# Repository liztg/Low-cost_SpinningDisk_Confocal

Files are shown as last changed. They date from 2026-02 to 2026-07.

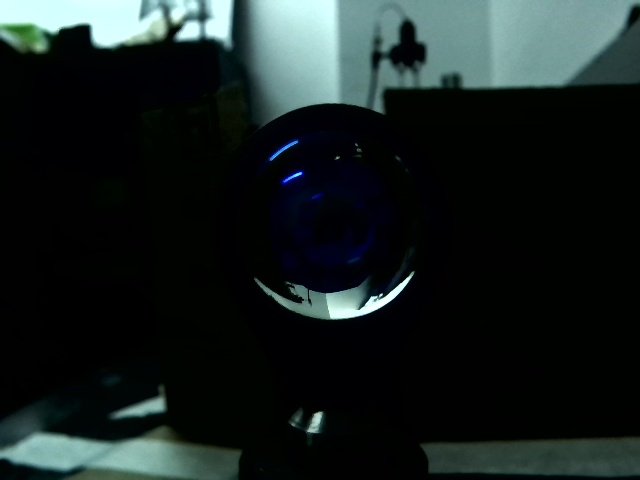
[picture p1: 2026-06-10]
Software/nipkowArduino/test/export/test_capture.jpg

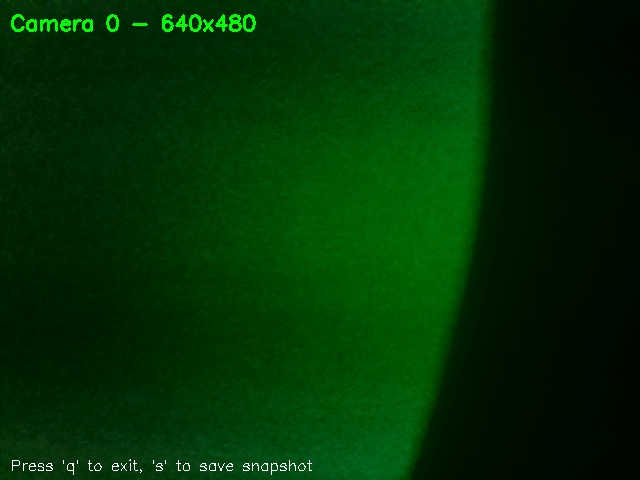
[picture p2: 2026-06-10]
Software/nipkowArduino/test/export/snapshot_20251127_172703_2.jpg

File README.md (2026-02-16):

SOFTWARE

The system integrates the control of a stepper motor (with a TB6560 driver through Arduino) and the acquisition of images with a USB camera from a unique Python interface.
It allows connecting and disconnecting devices, adjusting the motor velocity (between 0 and 300 RPM), showing live video, acquiring a series of images with manual exposure, and
to carry out different operations like average or sum to improve the signal, always saving the results with time stamps.

The software uses PySerial for the serial communication between the motor and Arduino. In controlling the camera, it uses opencv-python (OpenCV) for the detection, capture, and
visualization of images, and Numpy for the processing. It also uses standard utilities of Python, like Datetime for the names of the files and for time management.

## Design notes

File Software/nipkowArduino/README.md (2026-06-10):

# Arduino Stepper Motor & Camera Control System

Sistema integrado para control de motor stepper mediante Arduino con driver A4988 y captura de imágenes con cámara USB, controlado desde Python via comunicación serial.

## 📋 Componentes Necesarios

### Hardware Stepper
- Arduino (Uno, Nano, Mega, etc.)
- Driver TB6560 (o TB6600)
- Motor stepper (NEMA 17, NEMA 23, etc.)
- Fuente de alimentación (12-36V DC para el motor)
- Cables de conexión

### Hardware Cámara
- Cámara USB compatible con Windows
- Puerto USB disponible

## 🔌 Conexiones Hardware

### TB6560 a Arduino
```
TB6560 PUL+ (CLK+)  -> Arduino Pin 3
TB6560 DIR+ (CW+)   -> Arduino Pin 4
TB6560 ENA+         -> Arduino Pin 5 (opcional)
TB6560 PUL-         -> Arduino GND
TB6560 DIR-         -> Arduino GND
TB6560 ENA-         -> Arduino GND
```

### TB6560 a Motor y Alimentación
```
TB6560 VCC   -> Fuente de alimentación + (12-36V DC)
TB6560 GND   -> Fuente de alimentación -
TB6560 A+, A- -> Bobina A del motor
TB6560 B+, B- -> Bobina B del motor
```

### Configuración del TB6560
⚠️ **IMPORTANTE**: 
- **Ajustar corriente**: Usar los DIP switches según las especificaciones de tu motor
- **Microstepping**: Configurar según necesites (1, 2, 4, 8, 16 pasos)
- **Voltaje**: Verificar que la fuente esté dentro del rango 12-36V DC

## 🚀 Instalación

### 1. Clonar o descargar el proyecto
```bash
cd nipkowArduino
```

### 2. Instalar dependencias Python
```bash
pip install -r requirements.txt
```

### 3. Cargar código al Arduino
1. Abre `arduino_stepper/arduino_stepper.ino` en Arduino IDE
2. Conecta tu Arduino por USB
3. Selecciona el puerto COM correcto en Herramientas > Puerto
4. Haz clic en "Cargar" (Upload)

## 💻 Uso

### Ejecutar la Aplicación Principal

El sistema se controla mediante comandos de texto:

```bash
python main.py
```

### Interfaz de Comandos

```
>>> help

CONNECTION:
  connect <PORT>              - Connect to Arduino
  cam                         - Connect to camera (auto-detect)
  cam <INDEX>                 - Connect to specific camera
  disconnect                  - Disconnect all devices

STEPPER MOTOR:
  speed <RPM>                 - Set motor speed
  stop                        - Stop motor immediately
  status                      - Show motor status

CAMERA:
  capture <N> <EXP> avg       - Capture N images, exposure EXP ms, average
  capture <N> <EXP> sum       - Capture N images, exposure EXP ms, sum
  live                        - Show live video feed
  list-cam                    - List available cameras

SYSTEM:
  info                        - Show system status
  help                        - Show this help
  exit                        - Exit program
```

### Flujo de Trabajo Típico

#### 1. Conectar Dispositivos
```
>>> connect COM3
Connecting to COM3...
Connected to stepper on COM3

>>> cam
Connecting to camera...
Camera connected: Index 0, 1920x1080
```

#### 2. Controlar Motor Stepper
```
>>> speed 150
Arduino: Speed set to 150 RPM

>>> status
Motor Status:
   Speed: 150 RPM
   State: CW
   Running: Yes

>>> stop
Stopping motor...
Arduino: Speed set to 0 RPM
```

#### 3. Capturar y Procesar Imágenes
```
>>> capture 10 100 avg
Starting capture: 10 images @ 100ms...

Capturing 10 images with timing measurement...
============================================================
  Image 1/10 | Capture: 45.23ms | Interval: N/A (first)
  Image 2/10 | Capture: 43.87ms | Interval: 545.12ms
  ...
============================================================
CAPTURE STATISTICS
============================================================
Images captured: 10/10
Total burst time: 5.432s (5432.15ms)

INDIVIDUAL CAPTURE TIMES:
  Average: 44.28ms
  Min: 43.87ms
  Max: 45.67ms

INTER-CAPTURE INTERVALS:
  Average: 544.33ms
  Min: 543.98ms
  Max: 545.12ms

Effective FPS: 1.84
============================================================

Averaging 10 images...
Successfully averaged 10 images -> output_averaged_20251126_143052.jpg

Save timing statistics to file? (y/n): y
Statistics saved to: capture_stats_20251126_143052.txt
```

#### 4. Vista en Vivo
```
>>> live
Starting live video...
Controls:
  'q' or ESC - Exit live view
  's' - Save snapshot

[Ventana de OpenCV se abre]
[Presionar 's' para guardar snapshot]
Snapshot saved: snapshot_20251126_143215_1.jpg
[Presionar 'q' para salir]
```

#### 5. Ver Estado del Sistema
```
>>> info
==================================================
SYSTEM STATUS
==================================================
[OK] Stepper: Connected
  Speed: 0 RPM
  State: STOPPED
[OK] Camera: Connected (Index 0)
  Resolution: 1920x1080
==================================================
```

### Uso Avanzado - Módulos Independientes

#### Solo Control de Stepper
```bash
python stepper_control.py
```

#### Solo Control de Cámara
```bash
python camera_controller.py
```

## 🎯 Casos de Uso

### Fotografía de Larga Exposición
```
>>> cam
>>> capture 10 200 avg
```
1. Conectar cámara
2. Capturar 10 imágenes con exposición de 200ms
3. Promediar para reducir ruido
4. Resultado guardado automáticamente

### Astrofotografía
```
>>> cam
>>> capture 30 500 sum
```
1. Capturar 30 frames con exposición de 500ms
2. Sumar imágenes para aumentar señal
3. Resultado normalizado automáticamente

### Time-Lapse con Motor
```
>>> connect COM3
>>> cam
>>> speed 10
>>> capture 100 100 avg
>>> stop
```
1. Configurar stepper para rotación lenta (10 RPM)
2. Capturar 100 imágenes promediadas
3. Detener motor al finalizar

### Escaneo Panorámico
```
>>> connect COM3
>>> cam
>>> live              # Verificar encuadre primero
>>> speed 20
>>> capture 50 200 avg
>>> stop
```

## ⚙️ Configuración

### Parámetros de Cámara

#### Exposición Manual
- Rango típico: 1-1000 ms
- Para fotografía nocturna: 100-500 ms
- Para objetos en movimiento: 1-50 ms

#### Número de Imágenes
- Promediado (reducir ruido): 5-20 imágenes
- Suma (astrofotografía): 10-50 imágenes
- Más imágenes = mejor calidad pero más tiempo

### Cambiar Pasos por Revolución
Si tu motor tiene diferente número de pasos (por ejemplo, 400 pasos):

En `arduino_stepper.ino` línea 19:
```cpp
const int STEPS_PER_REVOLUTION = 200;  // Cambiar según tu motor
```

### Cambiar Pines
Modifica las definiciones en `arduino_stepper.ino` líneas 15-17:
```cpp
const int STEP_PIN = 3;   // PUL+ on TB6560
const int DIR_PIN = 4;    // DIR+ on TB6560
const int ENABLE_PIN = 5; // ENA+ on TB6560
```

### Cambiar Dirección de Rotación
En `arduino_stepper.ino` línea 26:
```cpp
digitalWrite(DIR_PIN, HIGH);  // HIGH = horario, LOW = antihorario
```

## 🔧 Resolución de Problemas

### Cámara

#### No se detecta la cámara
- Verifica que esté conectada al USB
- Prueba con otro puerto USB
- Cierra otras aplicaciones que puedan estar usando la cámara
- Verifica que los drivers estén instalados

#### Las imágenes salen muy oscuras/claras
- Ajusta el tiempo de exposición
- Valores más altos = más luz capturada
- Prueba con diferentes tiempos

#### Error al guardar imágenes
- Verifica permisos de escritura en el directorio
- Asegúrate de tener espacio en disco

### Motor Stepper
- Verifica las conexiones
- Comprueba que la alimentación del motor esté conectada
- Ajusta la corriente del A4988
- Verifica que ENABLE esté en LOW (motor habilitado)

#### El motor no gira
- Verifica las conexiones (PUL+, DIR+, ENA+ a Arduino y todos los - a GND)
- Comprueba que la alimentación del motor esté conectada (12-36V DC)
- Ajusta la corriente mediante DIP switches del TB6560
- Verifica que ENABLE esté en LOW (motor habilitado)
- Asegúrate de conectar correctamente PUL-, DIR-, ENA- a GND del Arduino

#### El motor vibra pero no gira
- La velocidad puede ser demasiado alta
- Reduce el RPM
- Ajusta la corriente mediante DIP switches del TB6560
- Verifica la configuración de microstepping
- Asegúrate de que las conexiones A+/A- y B+/B- sean correctas

#### Error al conectar por serial
- Verifica el puerto COM correcto
- Cierra otras aplicaciones que puedan estar usando el puerto (Arduino IDE Serial Monitor)
- Asegúrate de que los drivers del Arduino estén instalados

#### El motor pierde pasos
- Reduce la velocidad
- Ajusta la corriente del TB6560 (aumentar ligeramente)
- Verifica que la carga mecánica no sea excesiva
- Reduce el microstepping o aumenta el voltaje de alimentación

## 📝 Estructura del Proyecto

```
nipkowArduino/
├── main.py                     # Aplicación principal unificada
├── stepper_control.py          # Módulo control stepper
├── camera_controller.py        # Módulo control cámara
├── arduino_stepper/
│   └── arduino_stepper.ino     # Código Arduino
├── requirements.txt            # Dependencias Python
├── .gitignore
├── README.md
└── .github/
    └── copilot-instructions.md
```

## 📋 Referencia de Comandos

### Comandos de Conexión

| Comando | Descripción | Ejemplo |
|---|---|---|
| `connect <PORT>` | Conectar Arduino en puerto especificado | `connect COM3` |
| `cam` | Conectar cámara (auto-detecta) | `cam` |
| `cam <INDEX>` | Conectar cámara específica | `cam 0` |
| `disconnect` | Desconectar todos los dispositivos | `disconnect` |

### Comandos de Motor

| Comando | Descripción | Ejemplo |
|---|---|---|
| `speed <RPM>` | Establecer velocidad (0-300 RPM) | `speed 100` |
| `stop` | Parada de emergencia | `stop` |
| `status` | Ver estado del motor | `status` |

### Comandos de Cámara

| Comando | Descripción | Ejemplo |
|---|---|---|
| `capture <N> <EXP> avg` | Capturar N imágenes, promediar | `capture 10 100 avg` |
| `capture <N> <EXP> sum` | Capturar N imágenes, sumar | `capture 20 50 sum` |
| `live` | Vista en vivo | `live` |
| `list-cam` | Listar cámaras disponibles | `list-cam` |

### Comandos de Sistema

| Comando | Descripción | Ejemplo |
|---|---|---|
| `info` | Estado completo del sistema | `info` |
| `help` o `?` | Mostrar ayuda | `help` |
| `exit` o `quit` | Salir del programa | `exit` |

### Archivos Generados

| Archivo | Descripción |
|---|---|
| `output_averaged_YYYYMMDD_HHMMSS.jpg` | Imágenes promediadas |
| `output_summed_YYYYMMDD_HHMMSS.jpg` | Imágenes sumadas |
| `snapshot_YYYYMMDD_HHMMSS_N.jpg` | Snapshots desde live view |
| `capture_stats_YYYYMMDD_HHMMSS.txt` | Estadísticas de timing |

### Medición de Tiempos

Cada captura registra:
- **Tiempo individual** de cada imagen (ms)
- **Intervalo exacto** entre capturas consecutivas (ms)
- **Tiempo total** de la ráfaga (ms/s)
- **Estadísticas**: promedio, mínimo, máximo
- **FPS efectivo** de la captura

Ejemplo de estadísticas guardadas:
```
CAPTURE BURST STATISTICS
============================================================

Date/Time: 2025-11-26 14:30:52
Images captured: 10/10
Total burst time: 5.432156s (5432.156ms)

INDIVIDUAL CAPTURE TIMES (ms):
  Image 1: 45.234ms
  Image 2: 43.871ms
  Image 3: 44.012ms
  ...

AVERAGE: 44.283ms
MIN: 43.871ms
MAX: 45.671ms

INTER-CAPTURE INTERVALS (ms):
  Interval 1-2: 545.123ms
  Interval 2-3: 543.987ms
  ...

AVERAGE: 544.332ms
MIN: 543.987ms
MAX: 546.012ms

EFFECTIVE FPS: 1.841
```

## 🎓 Funcionalidades Principales

### Control de Stepper
- ✅ Comunicación serial bidireccional con Arduino
- ✅ Control de velocidad en RPM (0-300)
- ✅ Lectura de confirmaciones del Arduino
- ✅ Parada de emergencia
- ✅ Monitoreo de estado en tiempo real
- ✅ Interfaz por comandos de texto

### Control de Cámara
- ✅ Detección automática de cámaras USB
- ✅ Control de exposición manual
- ✅ Captura múltiple de imágenes
- ✅ Promediado de imágenes (reducir ruido)
- ✅ Suma de imágenes (aumentar señal)
- ✅ Vista en vivo con OpenCV
- ✅ Captura de snapshots durante live view
- ✅ Guardado automático con timestamp
- ✅ Normalización automática
- ✅ **Medición precisa de tiempos de captura**
- ✅ **Estadísticas detalladas de intervalos**
- ✅ **Exportación de estadísticas a archivo**

## 📚 Recursos Adicionales

- [Datasheet TB6560](https://www.epitran.it/ebayDrive/TB6560.pdf)
- [TB6600 Manual](https://www.dfrobot.com/wiki/index.php/TB6600_Stepper_Motor_Driver_SKU:_DRI0043)
- [PySerial Documentation](https://pyserial.readthedocs.io/)
- [OpenCV Python Tutorials](https://docs.opencv.org/4.x/d6/d00/tutorial_py_root.html)
- [Arduino Serial Reference](https://www.arduino.cc/reference/en/language/functions/communication/serial/)
- [NumPy Documentation](https://numpy.org/doc/)

## 🔬 Aplicaciones

- **Astrofotografía**: Captura y suma de múltiples exposiciones
- **Fotografía de larga exposición**: Reducción de ruido mediante promediado
- **Time-lapse**: Sincronización de motor y captura de imágenes
- **Escaneo panorámico**: Control preciso de rotación con captura
- **Microscopía**: Control de iluminación y captura automática

## 📄 Licencia

Este proyecto es de código abierto y está disponible bajo la licencia MIT.

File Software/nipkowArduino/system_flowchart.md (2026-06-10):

# Diagrama de Flujo del Sistema de Control

## Arquitectura General del Sistema

```mermaid
graph TB
    subgraph "Usuario"
        USER[Usuario]
    end
    
    subgraph "Aplicación Python - main.py"
        CLI[Interfaz de Comandos CLI]
        PARSER[Parser de Comandos]
        MAIN[MainController]
    end
    
    subgraph "Módulos de Control"
        STEPPER[StepperController]
        CAMERA[CameraController]
    end
    
    subgraph "Hardware"
        ARDUINO[Arduino + TB6560]
        MOTOR[Motor Stepper]
        CAM[Cámara USB]
    end
    
    subgraph "Salidas"
        IMG[Imágenes Procesadas]
        STATS[Estadísticas de Timing]
        SNAP[Snapshots]
    end
    
    USER -->|Comandos de texto| CLI
    CLI --> PARSER
    PARSER --> MAIN
    
    MAIN -->|Comandos de motor| STEPPER
    MAIN -->|Comandos de cámara| CAMERA
    
    STEPPER <-->|Serial 9600 baud| ARDUINO
    ARDUINO -->|Pulsos STEP/DIR| MOTOR
    
    CAMERA <-->|USB / OpenCV| CAM
    
    CAMERA --> IMG
    CAMERA --> STATS
    CAMERA --> SNAP
```

## Flujo de Inicio del Sistema

```mermaid
flowchart TD
    START([Ejecutar python main.py]) --> INIT[Inicializar MainController]
    INIT --> WELCOME[Mostrar mensaje de bienvenida]
    WELCOME --> PROMPT[Mostrar prompt: >>>]
    PROMPT --> WAIT{Esperar entrada<br/>de usuario}
    
    WAIT -->|Comando recibido| PARSE[Parsear comando]
    PARSE --> VALIDATE{¿Comando<br/>válido?}
    
    VALIDATE -->|No| ERROR[Mostrar error]
    ERROR --> PROMPT
    
    VALIDATE -->|Sí| DISPATCH[Despachar a handler]
    DISPATCH --> EXEC[Ejecutar comando]
    EXEC --> RESULT[Mostrar resultado]
    RESULT --> PROMPT
    
    WAIT -->|Ctrl+C o EOF| CLEANUP[Cleanup: cerrar dispositivos]
    CLEANUP --> END([Salir])
```

## Flujo de Conexión de Dispositivos

```mermaid
flowchart TD
    subgraph "Conexión Arduino"
        CONN_START[Comando: connect COM3] --> OPEN_SERIAL[Abrir puerto serial]
        OPEN_SERIAL --> WAIT_RESET[Esperar 2s para reset]
        WAIT_RESET --> READ_INIT[Leer mensaje inicial]
        READ_INIT --> CONN_OK[Stepper conectado]
    end
    
    subgraph "Conexión Cámara"
        CAM_START[Comando: cam] --> DETECT[Detectar cámaras USB]
        DETECT --> CHECK{¿Cámaras<br/>encontradas?}
        CHECK -->|No| CAM_ERROR[Error: sin cámaras]
        CHECK -->|Sí| SELECT[Seleccionar cámara]
        SELECT --> OPEN_CAM[Abrir VideoCapture]
        OPEN_CAM --> GET_INFO[Obtener resolución/info]
        GET_INFO --> CAM_OK[Cámara conectada]
    end
```

## Flujo de Control de Motor Stepper

```mermaid
flowchart TD
    SPEED_CMD[Comando: speed 150] --> CHECK_CONN{¿Stepper<br/>conectado?}
    CHECK_CONN -->|No| ERR1[Error: no conectado]
    
    CHECK_CONN -->|Sí| VALIDATE_RPM{¿RPM válido<br/>0-300?}
    VALIDATE_RPM -->|No| ERR2[Advertencia: valor fuera de rango]
    ERR2 --> CLAMP[Ajustar a rango válido]
    
    VALIDATE_RPM -->|Sí| CLAMP
    CLAMP --> BUILD_CMD[Construir comando: SPEED:150]
    BUILD_CMD --> SEND[Enviar por serial]
    SEND --> FLUSH[Flush buffer]
    FLUSH --> WAIT_RESP[Esperar respuesta Arduino]
    
    WAIT_RESP --> READ{¿Respuesta<br/>recibida?}
    READ -->|No| TIMEOUT[Advertencia: sin respuesta]
    READ -->|Sí| PARSE_RESP[Parsear respuesta]
    PARSE_RESP --> UPDATE[Actualizar estado interno]
    UPDATE --> SHOW[Mostrar confirmación]
    
    subgraph "Arduino"
        ARD_RECV[Recibir comando serial] --> ARD_PARSE[Parsear SPEED:XXX]
        ARD_PARSE --> ARD_CALC[Calcular delay entre pasos]
        ARD_CALC --> ARD_SET[Configurar stepDelay]
        ARD_SET --> ARD_SEND[Enviar confirmación]
        ARD_SEND --> ARD_LOOP[Loop: generar pulsos STEP]
    end
```

## Flujo de Captura de Imágenes

```mermaid
flowchart TD
    CAPTURE_CMD[Comando: capture 10 100 avg] --> PARSE_ARGS[Parsear argumentos]
    PARSE_ARGS --> EXTRACT[Extraer: N=10, EXP=100ms, MODE=avg]
    
    EXTRACT --> CHECK_CAM{¿Cámara<br/>conectada?}
    CHECK_CAM -->|No| ERR_CAM[Error: cámara no conectada]
    
    CHECK_CAM -->|Sí| SET_EXP[Configurar exposición manual]
    SET_EXP --> WAIT_CAM[Esperar ajuste de cámara 0.5s]
    WAIT_CAM --> INIT_STATS[Inicializar arrays de estadísticas]
    
    INIT_STATS --> START_TIMER[Iniciar timer de ráfaga]
    START_TIMER --> LOOP_START{i < N?}
    
    LOOP_START -->|No| LOOP_END[Fin de captura]
    LOOP_START -->|Sí| TIMER1[Timestamp inicial]
    
    TIMER1 --> CAP[Capturar imagen]
    CAP --> TIMER2[Timestamp final]
    TIMER2 --> CALC_TIME[Calcular tiempo de captura]
    CALC_TIME --> STORE_IMG[Guardar imagen en array]
    STORE_IMG --> STORE_TIME[Guardar tiempo en array]
    
    STORE_TIME --> CALC_INT{¿i > 0?}
    CALC_INT -->|Sí| CALC_INTERVAL[Calcular intervalo desde anterior]
    CALC_INTERVAL --> STORE_INT[Guardar intervalo]
    CALC_INT -->|No| SKIP_INT[Intervalo = N/A]
    
    STORE_INT --> PRINT[Imprimir estadísticas de imagen]
    SKIP_INT --> PRINT
    PRINT --> DELAY[Delay entre capturas]
    DELAY --> INCREMENT[i++]
    INCREMENT --> LOOP_START
    
    LOOP_END --> END_TIMER[Finalizar timer total]
    END_TIMER --> CALC_STATS[Calcular estadísticas]
    CALC_STATS --> PRINT_STATS[Imprimir estadísticas completas]
    
    PRINT_STATS --> PROCESS{Modo de<br/>procesamiento}
    PROCESS -->|avg| AVG[Promediar imágenes]
    PROCESS -->|sum| SUM[Sumar imágenes]
    
    AVG --> SAVE_IMG[Guardar imagen procesada]
    SUM --> SAVE_IMG
    
    SAVE_IMG --> ASK{¿Guardar<br/>estadísticas?}
    ASK -->|Sí| SAVE_STATS[Guardar archivo .txt]
    ASK -->|No| DONE[Finalizado]
    SAVE_STATS --> DONE
```

## Flujo de Vista en Vivo (Live View)

```mermaid
flowchart TD
    LIVE_CMD[Comando: live] --> CHECK_CAM{¿Cámara<br/>conectada?}
    CHECK_CAM -->|No| ERR[Error: cámara no conectada]
    
    CHECK_CAM -->|Sí| SHOW_INST[Mostrar instrucciones]
    SHOW_INST --> WAIT_USER[Esperar usuario presione tecla]
    WAIT_USER --> INIT_WIN[Crear ventana OpenCV]
    
    INIT_WIN --> LOOP{Loop infinito}
    LOOP --> READ_FRAME[Leer frame de cámara]
    READ_FRAME --> CHECK_FRAME{¿Frame<br/>válido?}
    
    CHECK_FRAME -->|No| ERR_FRAME[Error: frame inválido]
    ERR_FRAME --> EXIT
    
    CHECK_FRAME -->|Sí| OVERLAY[Agregar info overlay]
    OVERLAY --> DISPLAY[Mostrar en ventana]
    DISPLAY --> KEY[Leer tecla con waitKey(1)]
    
    KEY --> CHECK_KEY{¿Qué tecla?}
    CHECK_KEY -->|'q' o ESC| EXIT[Salir de live view]
    CHECK_KEY -->|'s'| SNAP[Guardar snapshot]
    CHECK_KEY -->|Otra| LOOP
    
    SNAP --> GEN_NAME[Generar nombre con timestamp]
    GEN_NAME --> SAVE_SNAP[Guardar snapshot]
    SAVE_SNAP --> PRINT_SNAP[Imprimir confirmación]
    PRINT_SNAP --> LOOP
    
    EXIT --> DESTROY[Destruir ventanas OpenCV]
    DESTROY --> CLEAR[Limpiar buffers]
    CLEAR --> DONE[Retornar a prompt]
```

## Flujo de Procesamiento de Imágenes

```mermaid
flowchart TD
    START[Array de imágenes capturadas] --> CHECK{¿Modo de<br/>procesamiento?}
    
    subgraph "Promediado (avg)"
        AVG_START[Modo: average] --> CONVERT_F[Convertir a float]
        CONVERT_F --> MEAN[np.mean(images, axis=0)]
        MEAN --> CONVERT_U8[Convertir a uint8]
        CONVERT_U8 --> AVG_RESULT[Imagen promediada]
    end
    
    subgraph "Suma (sum)"
        SUM_START[Modo: sum] --> SUM_F[Sumar como float64]
        SUM_F --> NORMALIZE{¿Normalizar?}
        NORMALIZE -->|Sí| NORM[Normalizar 0-255]
        NORMALIZE -->|No| CLIP[Clip 0-255]
        NORM --> SUM_RESULT[Imagen sumada]
        CLIP --> SUM_RESULT
    end
    
    CHECK -->|avg| AVG_START
    CHECK -->|sum| SUM_START
    
    AVG_RESULT --> SAVE
    SUM_RESULT --> SAVE
    
    SAVE[cv2.imwrite] --> TIMESTAMP[Generar nombre con timestamp]
    TIMESTAMP --> FILE[Guardar archivo JPG]
```

## Estados del Sistema

```mermaid
stateDiagram-v2
    [*] --> Desconectado
    
    Desconectado --> StepperConectado: connect COM3
    Desconectado --> CamaraConectada: cam
    
    StepperConectado --> Ambos: cam
    CamaraConectada --> Ambos: connect COM3
    
    StepperConectado --> MotorActivo: speed > 0
    MotorActivo --> StepperConectado: speed 0 / stop
    
    CamaraConectada --> Capturando: capture
    Capturando --> CamaraConectada: fin de captura
    
    CamaraConectada --> VistaEnVivo: live
    VistaEnVivo --> CamaraConectada: 'q' / ESC
    
    Ambos --> MotorYCaptura: speed > 0 && capture
    MotorYCaptura --> Ambos: fin
    
    StepperConectado --> Desconectado: disconnect
    CamaraConectada --> Desconectado: disconnect
    Ambos --> Desconectado: disconnect
    MotorActivo --> Desconectado: disconnect (auto-stop)
    
    Desconectado --> [*]: exit
    StepperConectado --> [*]: exit
    CamaraConectada --> [*]: exit
    Ambos --> [*]: exit
```

## Diagrama de Secuencia - Captura Completa

```mermaid
sequenceDiagram
    actor Usuario
    participant CLI as CLI/Main
    participant Camera as CameraController
    participant USB as Cámara USB
    participant File as Sistema de Archivos
    
    Usuario->>CLI: capture 10 100 avg
    CLI->>Camera: capture_multiple(10, 100)
    Camera->>USB: set_exposure(100)
    USB-->>Camera: OK
    
    Note over Camera: Espera 0.5s
    
    loop Para cada imagen (i=1..10)
        Camera->>Camera: timestamp_start
        Camera->>USB: read()
        USB-->>Camera: frame
        Camera->>Camera: timestamp_end
        Camera->>Camera: calcular tiempo
        Camera->>Camera: guardar en array
        Camera->>CLI: Image i/10 | 45ms | 544ms
        Note over Camera: Delay 0.5s
    end
    
    Camera->>Camera: calcular estadísticas
    Camera->>CLI: CAPTURE STATISTICS
    CLI->>Usuario: Mostrar stats
    
    Camera->>Camera: average_images(array)
    Camera->>File: save_image(result)
    File-->>Camera: OK
    
    Camera->>CLI: Resultado guardado
    CLI->>Usuario: ¿Guardar estadísticas? (y/n)
    Usuario->>CLI: y
    CLI->>Camera: save_capture_stats()
    Camera->>File: write stats.txt
    File-->>Camera: OK
    Camera->>CLI: Stats guardadas
```

## Diagrama de Componentes

```mermaid
graph TB
    subgraph "Capa de Presentación"
        CLI[CLI Interface]
        HELP[Help System]
    end
    
    subgraph "Capa de Lógica"
        MAIN[MainController]
        PARSER[Command Parser]
        DISPATCH[Command Dispatcher]
    end
    
    subgraph "Capa de Control de Hardware"
        STEPPER[StepperController]
        CAMERA[CameraController]
    end
    
    subgraph "Capa de Comunicación"
        SERIAL[PySerial]
        OPENCV[OpenCV]
    end
    
    subgraph "Capa de Procesamiento"
        IMG_PROC[Image Processing]
        STATS[Statistics Calculator]
        TIMING[Timing Measurement]
    end
    
    subgraph "Capa de Persistencia"
        FILE_IO[File I/O]
        IMG_SAVE[Image Saver]
        STATS_SAVE[Stats Saver]
    end
    
    CLI --> MAIN
    HELP --> CLI
    MAIN --> PARSER
    PARSER --> DISPATCH
    
    DISPATCH --> STEPPER
    DISPATCH --> CAMERA
    
    STEPPER --> SERIAL
    CAMERA --> OPENCV
    
    CAMERA --> IMG_PROC
    CAMERA --> STATS
    CAMERA --> TIMING
    
    IMG_PROC --> IMG_SAVE
    STATS --> STATS_SAVE
    
    IMG_SAVE --> FILE_IO
    STATS_SAVE --> FILE_IO
```

## Leyenda de Símbolos

- **Rectángulos**: Procesos o acciones
- **Rombos**: Decisiones o condiciones
- **Círculos**: Puntos de inicio/fin
- **Flechas sólidas**: Flujo de control
- **Flechas punteadas**: Flujo de datos
- **Subgraphs**: Agrupación de componentes relacionados

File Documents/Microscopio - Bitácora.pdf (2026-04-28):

Microscopio Confocal de Disco Rotante de Bajo Costo Bitácora

Septiembre 2025:

Se realizó una revisión en la literatura sobre la fabricación de sistemas de microscopios confocales de bajo costo. A partir de ella se decidió como mejor opción por su bajo costo, por accesibilidad a recursos, y por su facilidad en el sistema de barrido (en comparación a otros tipos), fabricar un Microscopio Confocal de Disco Rotante. Su fabricación se basa en la publicación: A. R. Halpern, M. Y. Lee, M. D. Howard, M. A. Woodworth, P. R. Nicovich, and
J. C. Vaughan, “Versatile. doit-yourself, low-cost spinning disk confocal microscope,” Biomedical Optics Express, vol. 13, Feb. 2022.

Se realizó un esquema del sistema a fabricar utilizando elementos con los que ya se contaba en el laboratorio. Se decide utilizar como base de la estructura del dispositivo rieles de aluminio de 2cm de lado y como componentes principales, un láser de 520 nm de longitud de onda como fuente de iluminación, un objetivo de microscopio óptico de 40x, un posicionador mecánico para la muestra provisional y un módulo de cámara IMX179.

Se decide iniciar con la fabricación del disco de pinholes por medio de la técnica de litografía. Se calcula la distribución y tamaño de los pinholes según los parámetros correspondientes y se diseña la imagen a imprimir. Se empiezan a realizar pruebas correspondientes de menor tamaño en la empresa Colombian Imaging Technologies. Utilizando como primer procedimiento de prueba la deposición de una capa de photoresist por medio de spin coating sobre un sustrato de vidrio, el cual se expone con la imagen, se revela, y seguidamente se recubre con plata por medio de evaporación física para luego retirar el photoresist de la capa intermedia de las zonas de los pinholes con su solvente.

Octubre 2025:

Los resultados de las pruebas de fabricación de los pinholes no dan buenos resultados, por lo que se decide cambiar su proceso de fabricación. En lugar de cubrir primero el sustrato de vidrio con el photoresist, se cubre en primer lugar con una capa plata y sobre ella se deposita el photoresist, luego se expone con la imagen de los pinholes, se revela y se retira la plata de las zonas libres. Se realizan pruebas con diferentes compuestos en diferentes concentraciones para retirar la plata obteniendo como mejor resultado el uso de una solución formada por amoníaco, peróxido de hidrógeno y agua destilada en una proporción de 1:1:2. Después de conseguir pruebas satisfactorias se procede a fabricar el primer disco de pinholes. Se observa que la remoción de la plata no es perfecta, donde no todos los pinholes se observan bien descubiertos(? por lo que se deja como trabajo a futuro la optimización de la solución, su concentración y tiempo de revelado utilizado para mejorarla.

Se continua con el diseño del microscopio calculando las diferentes distancias a las que se deben situar los diferentes componentes del sistema. Se consiguen los lentes y demás componentes necesarios, como lo son la máscara cuadrada y el espejo divisor de haz. Se consigue un motor paso a paso NEMA con su controlador para realizar el giro (? del disco. Se empiezan a diseñar las diferentes piezas para fabricar por medio de mecanizado como los postes para sostener los elementos y poder variar su posición vertical, y los acoples del espejo y del objetivo. Además se diseñan también piezas en prototipado 3D como son los acoples de los postes, de la máscara cuadrada, del motor y de la cámara al riel, así como el acople del disco de pinholes al motor y el acople de la fibra óptica del láser.

Noviembre 2025:

Se imprimen las piezas y se colocan los insertos metálicos en las que lo requieran. Con todos los componentes listos se empieza a montar todo sobre los rieles, a excepción del posicionador mecánico. Todo se posiciona sobre una lámina metálica y se sostiene temporalmente con imanes para evitar movimientos.

Al mismo tiempo se empieza a diseñar un sistema de control que maneje la toma de imágenes y la velocidad y paso del motor. Se realizan pruebas tanto del giro del disco con el motor para verificar el acople y el control de velocidad, y así cómo de la toma de imagen.

Se ajustan las distancias de los diferentes componentes del dispositivo, se alinea todo el sistema de la mejor manera para obtener imagen y se colocan barreras para disminuir la luz dispersada.

Diciembre 2025:

Se utiliza como muestra de prueba un espejo que se sujeta al posicionador. Se realizan las primeras tomas de imágenes con el disco estático. Se logran observar los pinholes del disco enfocados en el espejo. Aún así, se observa una distribución de iluminación no muy uniforme y una estabilidad del sistema escasa causada por la lámina metálica. Al observar el haz colimado que proviene de la fibra óptica se observa una iluminación no uniforme, con manchas. Se revisa la fibra, y se le realiza una limpieza junto con el acople del láser sin encontrar mejoría. Se supone que es un problema intrínseco al láser utilizado. Se propone cambiar la fuente de iluminación antes de realizar más toma de imágenes.

Febrero - Abril 2026

Se cambia la fuente de iluminación por un array de leds de 4x4mm de 532nm que producen una potencia, según su documentación de 20W. Se observan problemas para colimar al tratarse de una fuente extendida. Se realizan diferentes pruebas para obtener el mejor haz colimado posible sin obtener un buen resultado. Se propone no continuar con el led y volver a utilizar un láser.

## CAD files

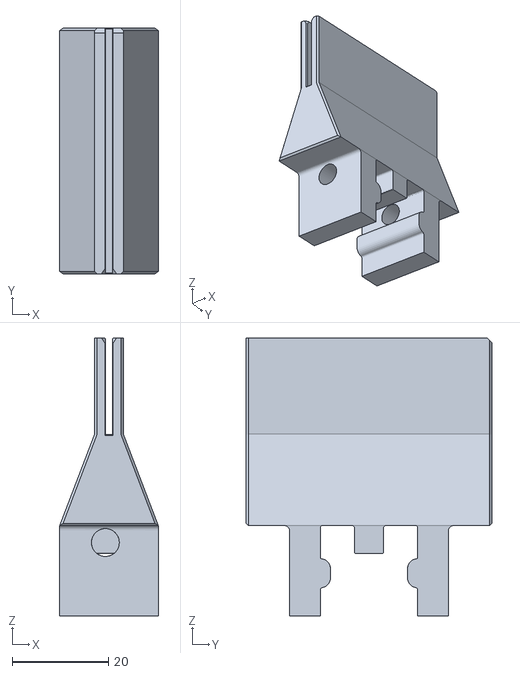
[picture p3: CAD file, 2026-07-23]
Hardware/stl/Soporte Polarizador.stl
20.5 x 51.0 x 57.7

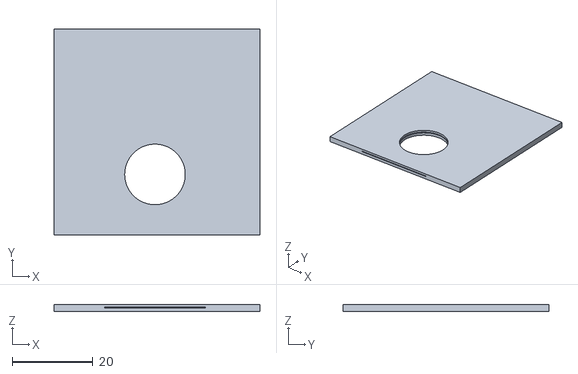
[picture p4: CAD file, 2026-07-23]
Hardware/stl/Marco Polarizador.stl
51.0 x 51.0 x 1.75

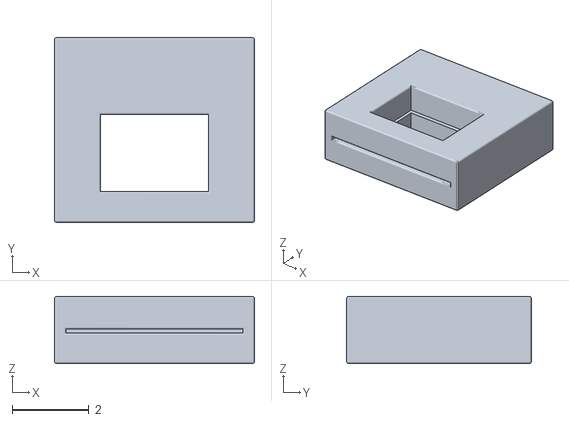
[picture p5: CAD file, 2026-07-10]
Hardware/stl/Marco Polarizador 1.stl
5.20 x 4.80 x 1.75

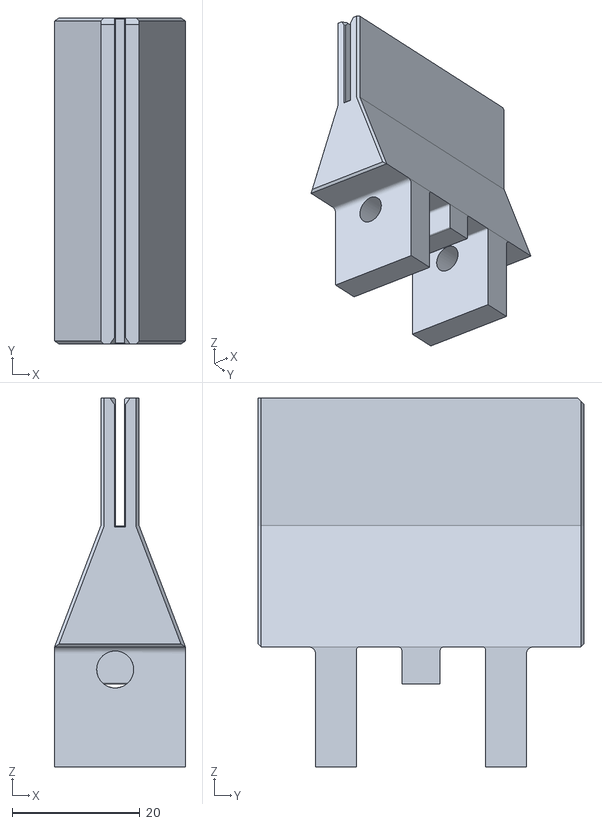
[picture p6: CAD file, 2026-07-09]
Hardware/stl/Soporte Marco Polarizador.stl
20.5 x 51.0 x 57.7

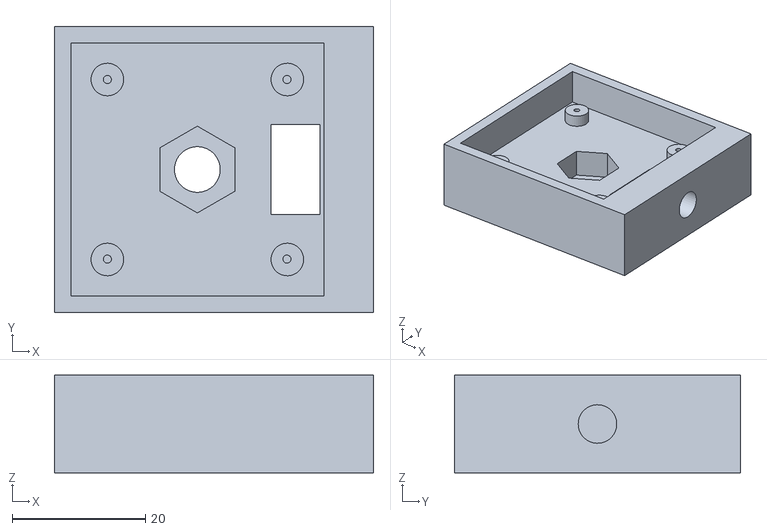
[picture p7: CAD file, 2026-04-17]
Hardware/stl/Caja Soporte Cámara.stl
47.9 x 42.9 x 14.7

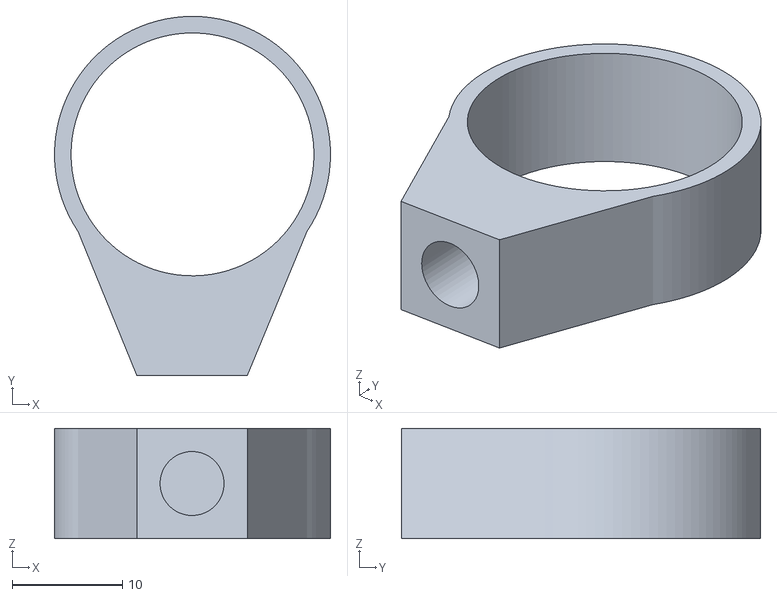
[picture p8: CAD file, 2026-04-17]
Hardware/stl/Soporte Objetivo.stl
25.0 x 32.5 x 10.0

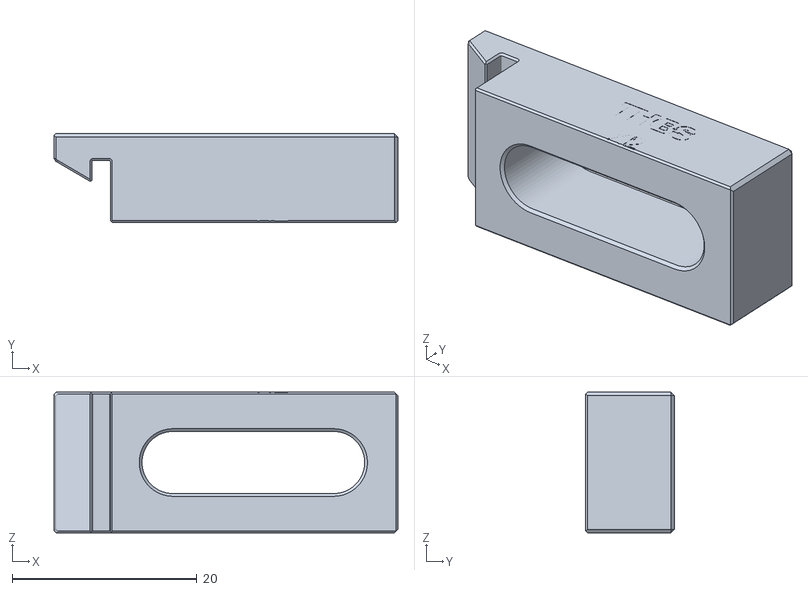
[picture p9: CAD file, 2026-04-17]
Hardware/stl/Acople Riel-Mesa.stl
37.3 x 9.65 x 15.2

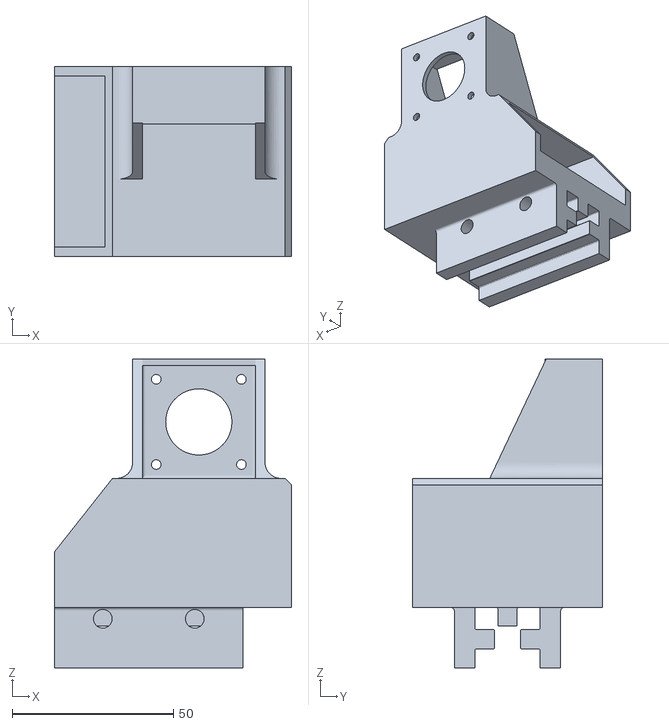
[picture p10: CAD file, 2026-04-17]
Hardware/stl/Soporte Motor Disco.stl
73.5 x 59.0 x 95.8

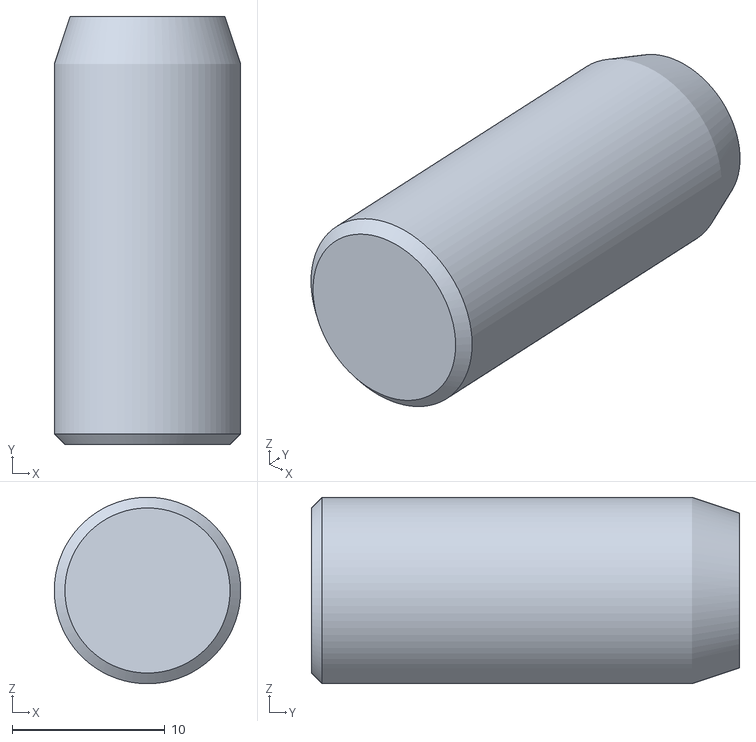
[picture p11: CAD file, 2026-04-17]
Hardware/stl/Poste.stl
12.2 x 28.0 x 12.2

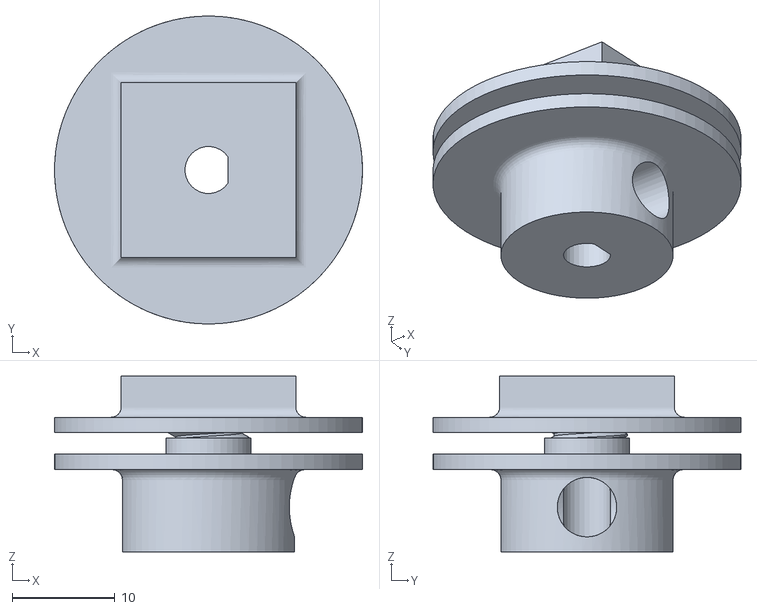
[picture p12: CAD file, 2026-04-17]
Hardware/stl/Acople Disco-Motor v2.stl
30.0 x 30.0 x 17.1

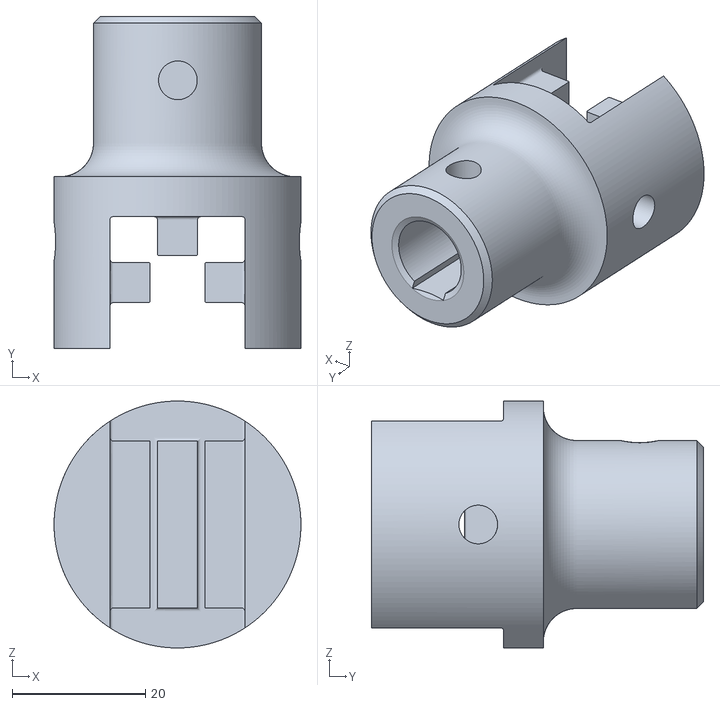
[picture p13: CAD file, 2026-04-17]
Hardware/stl/Soporte Poste.stl
37.0 x 49.7 x 37.0

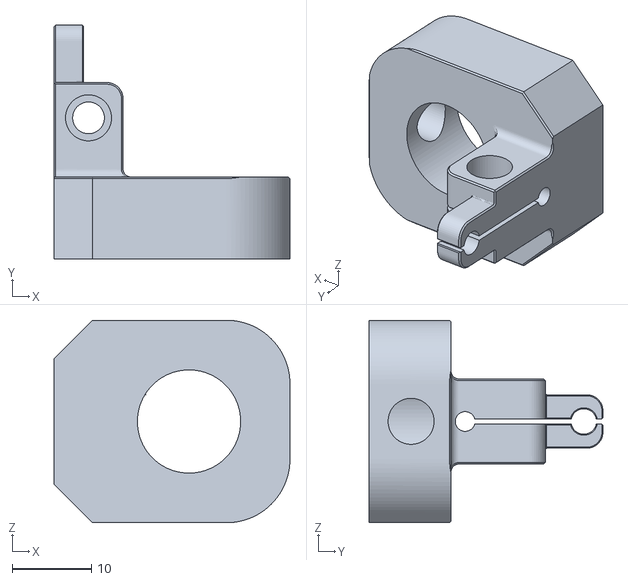
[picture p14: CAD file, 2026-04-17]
Hardware/stl/Soporte Fibra Imp3D.stl
29.7 x 29.5 x 25.5

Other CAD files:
Hardware/stl/Soporte Máscara Cuadrada.stl

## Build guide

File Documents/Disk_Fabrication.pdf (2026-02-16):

Trabajo de Grado | 16 de febrero de 2026

Fabricación de un Disco de Nipkow por Técnicas Litográficas

Lizeth T. González Vargas¹

and John W. Sandino del Busto¹ 1Departamento de Física,
Universidad Nacional de Colombia, Bogotá, Colombia

Abstract

Se fabricó un disco de Nipkow funcional para ser utilizado en un microscopio confocal de disco rotante, por medio de un procedimiento que permite la microfabricación de patrones de plata mediante litografía. Se obtuvo una buena estructura de los pinholes, con bordes bien definidos y de tamaño esperado. Sin embargo, se evidenció que no todos se revelan de manera uniforme, lo que ocasiona que una fracción de ellos permanezca parcialmente o totalmente sin destapar. Como trabajo futuro, se propone realizar una caracterización detallada del proceso de caracterización y llevar a cabo pruebas de oxidación o sulfuración del recubrimiento de plata con el fin de disminuir su reflectividad.

Palabras Clave: Disco de Nipkow/Petráň, Litografía, Microfabricación, Microscopio Confocal de Disco Rotante

I. INTRODUCCION´

El disco de Nipkow fue desarrollado por el inventor Paul Nipkow en 1884 como una forma de descomponer una imagen en una señal lineal analógica que pudiese ser transmitida electrónicamente y ser luego reconstruida en otro lugar [1]. Este consistía en una serie de cuadrados pequeños distribuidos en un disco en arreglo de una espiral de Arquímedes; al rotar el disco, la luz de un objeto transmitida a través de los cuadrados permitía su escaneo. Esta invención dio paso a la primera demostración de la televisión.
En 1967, el disco de Nipkow resurgió cuando David Egger y Mojmír Petráň crearon una versión más avanzada para ser utilizada en el primer microscopio confocal de disco rotante [2]. Contrario al disco original de Nipkow, este disco, ahora conocido como disco de Petráň, contenía aperturas circulares o pinholes en múltiples espirales de Arquímedes en lugar de una sola. Esto permitió obtener un microscopio confocal en el cual, en lugar de tener sólo un punto de enfoque en la muestra, se podían tener varios en paralelo, lo que permitió obtener mayor velocidad de escaneo [1].
A. Halpern et al. (2022) diseñaron un módulo de microscopio confocal de disco rotante de bajo costo donde utilizaron un disco de pinholes fabricado por un proceso fotolitográfico comercial utilizando una máscara de cromo [3]. D.T. Fewer et al. (1998) realizaron un estudio para evaluar el uso de una fuente coherente en el desempeño de microscopios de tipo de disco rotante utilizando como arreglo de pinholes una máscara fabricada por litografía por haz de electrones a partir de un sustrato con recubrimiento de cromo [4].

II. METODOLOGÍA

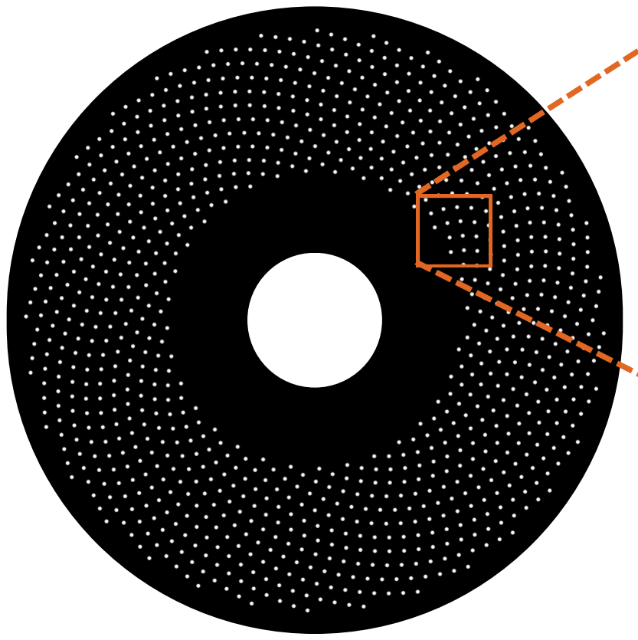
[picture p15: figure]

Figura 1: Diagrama de la distribución de pinholes en un arreglo de espirales de Arquímedes.

Los pinholes en el disco de Nipkow/Petráň se encuentran distribuidos en un arreglo de espirales de Arquímedes. A pesar de que una sola espiral es suficiente para hacer un barrido, el uso de varias espirales permite obtener una sensibilidad menor frente al desplazamiento del mismo respecto a su centro [3]. Un conjunto de n espirales está definido por la expresión matemática en coordenadas polares mostrada en 1, donde i hace referencia a la i-ésima espiral, rstart al radio inicial, n al número total de espirales y s al espaciamiento entre ellas. La figura 1 muestra un diagrama de cómo se ven los pinholes en la distribución de espirales de Arquímedes.

ri = rstart +

ns
2π
θ +

2πi
n
(1)

El disco se diseñó para ser fabricado sobre un disco de vidrio de 10cm de diámetro exterior y 1cm de diámetro interno. Los pinholes se distribuyen en el disco sobre un anillo de 2,5cm de radio interno y un grosor de 1,5cm, quedando así a 1cm del borde. Se decidió utilizar 32 espirales; el diámetro de los pinholes se definió en un valor de 38µm y su separación s igual a 190µm. Los valores de estos parámetros dependen de características del diseño del microscopio confocal de disco rotante, como lo son la longitud de onda y el objetivo a utilizar. Los respectivos cálculos se encuentran en el documento titulado “Diseño y Fabricación de un Microscopio Confocal de Disco Rotante a Bajo Costo” escrito como parte de este trabajo de grado, en el cual los cálculos se basan los mostrados por A. Halpern et al. en su publicación [3].

Plata
Sustrato de Vidrio

Photoresist Positivo

1. Depósito de capas | 2. Exposición con luz azul
3. Revelado del photoresist | 4. Remoción de plata

Figura 2: Diagrama del proceso realizado para la microfabricación del arreglo de pinholes.

La fabricación del disco se realizó en la empresa Combustión Ingenieros S.A.S. utilizando técnicas litográficas. El proceso realizado se muestra en la figura 2. Como sustrato se utiliza un disco de vidrio común previamente cortado, al que se le realiza una limpieza rigurosa. Este se recubre con una película de plata depositada por medio de la técnica de deposición física de vapor utilizando 0,5g de plata. Luego, se recubre con una película de photoresist positivo [5] por medio de la técnica de spin coating a aproximadamente 4000 rev/s para obtener un espesor aproximado de 1µm.
A continuación, se realiza la exposición de solamente la región de los pinholes con luz azul utilizando una máquina de litografía. Las regiones expuestas son removidas por medio del revelador, obteniendo pinholes sin photoresist, pero aún con plata. Finalmente, para la remoción de la plata se utiliza una solución de amoníaco (NH3), peróxido de hidrógeno (H2O2) y agua destilada en una proporción de 1 : 1 : 12. Se sumerge el disco y se agita suavemente por aproximadamente 2min.
La reacción química que se lleva a cabo se muestra en la expresión 2 [6]; el peróxido de hidrógeno oxida la plata generando iones Ag⁺ que reaccionan inmediatamente con el amoníaco generando cationes complejos diamino plata
(I) que son altamente solubles.

2Ag + 4NH3 + H2O2 −→ 2Ag(NH3)2

++ 2OH⁻ (2)

III. RESULTADOS Y ANALISIS ´

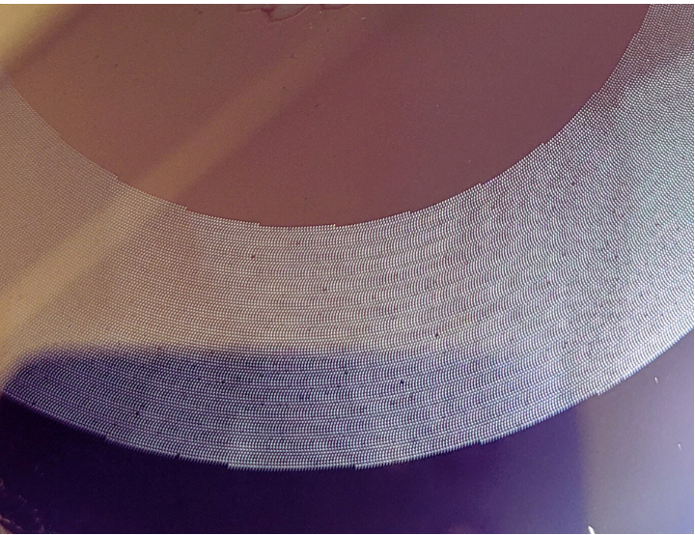
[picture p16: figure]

Figura 3: Fotografía del disco con el arreglo de pinholes ya fabricado.

En la figura 4 se observan imágenes tomadas del disco fabricado bajo el microscopio óptico a diferentes magnificaciones. Se observa la mayor parte de pinholes destapados donde su tamaño se excede en unas cuantas micras del tamaño esperado formado por el photoresist (circunferencia oscura). Esto se debe a la concentración de la solución de amoníaco y al tiempo que se sumerge la muestra en la solución.
Fue evidente, en pruebas realizadas con anterioridad utilizando diferentes concentraciones de la solución, que los pinholes no se ”destapan”de manera uniforme, es decir, algunos se demoran más tiempo en remover que otros. Al usar una solución más concentrada, los pinholes que se destapan más fácilmente crecen en tamaño más rápido si se deja la muestra más tiempo dentro de la solución, ya que empieza a remover horizontalmente la plata. Utilizando una solución más diluida, como la de esta prueba, se puede dar más tiempo a los pinholes que no se destapan tan rápido, mientras que los demás no aumentan de tamaño de forma acelerada. En la figura 3 se observa una fotografía del disco fabricado. Se observa el anillo de color más claro donde se encuentran las espirales de pinholes.
Entre las dificultades encontradas en su fabricación se encuentra la afectación que ocasionó la solución utilizada para la remoción de plata a los bordes del disco, levantando en ciertas partes la plata con el photoresist. Esto puede ser causa de la agresividad de la concentración utilizada. Además de esto, se evidenció que una fracción de

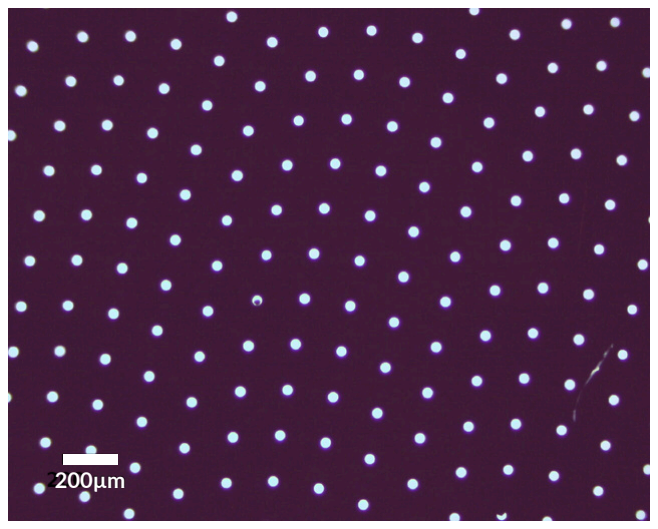
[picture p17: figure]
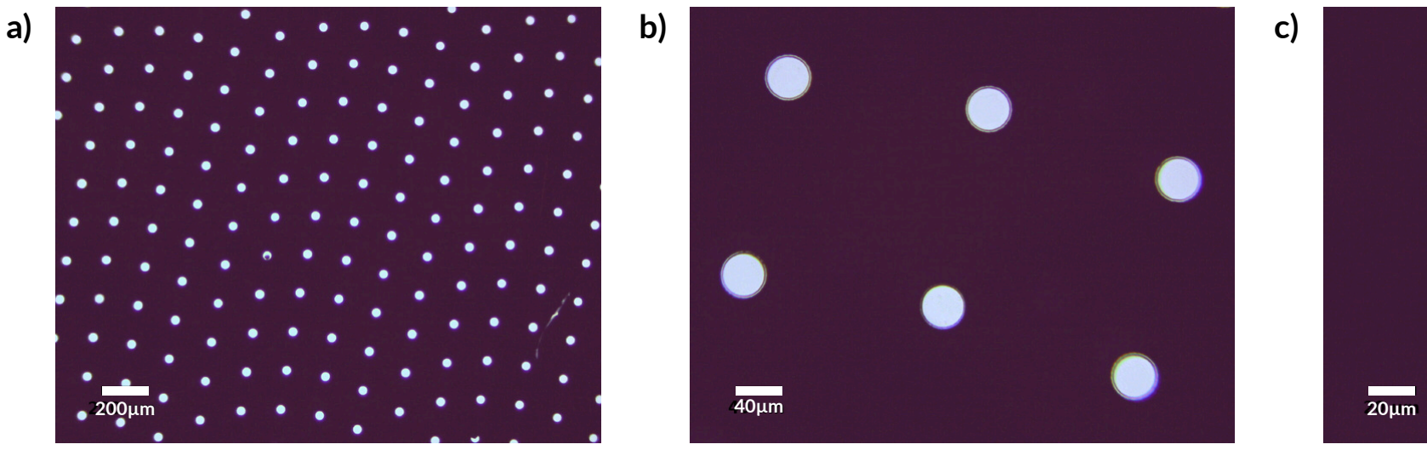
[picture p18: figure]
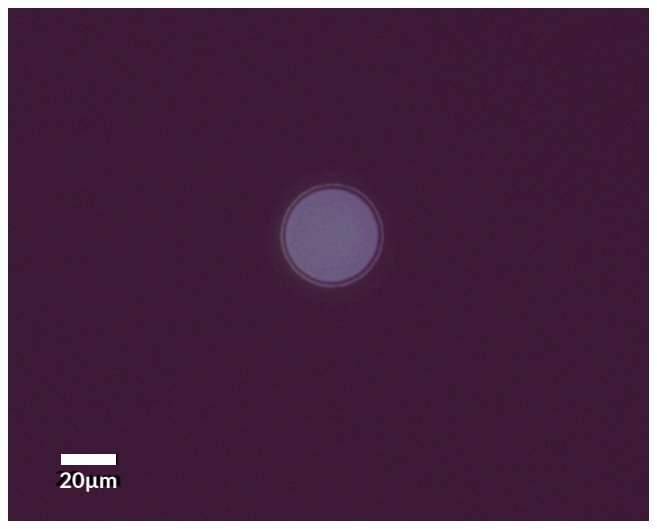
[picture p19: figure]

Figura 4: Imágenes a diferente magnificación del arreglo de pinholes fabricado. Se observan a a) 4x , b) 20x y c) 40x de magnificación.

los pinholes permaneció parcialmente o totalmente sin destapar, como se muestra en la figura 5. Esto sugiere poca uniformidad en el recubrimiento de plata o en la acción de la solución. Por esta razón, se planea realizar a futuro una caracterización más detallada del proceso para ser mejorado.

Una característica relevante del disco fabricado es que, al estar recubierto con plata, presenta una superficie altamente reflectante. Esto presenta un inconveniente en el diseño del microscopio confocal, ya que la luz reflejada puede llegar al sensor que capta la imagen y afectar la medida. Para las primeras pruebas, se inclinará el disco unos pocos grados con el fin de desviar dicha luz fuera del camino óptico. Sin embargo, a futuro se planea realizar tratamientos de oxidación o sulfuración del recubrimiento para disminuir su reflectividad.

IV. CONCLUSIONES Y DISCUSION´

Se diseñó un proceso que permite la microfabricación de patrones de plata mediante litografía. Con este se logró fabricar un disco de Nipkow funcional, que consiste en un arreglo de pinholes, para uso en un microscopio confocal de disco rotante.

Se evidenció que el proceso utilizado genera un buena estructura de los pinholes, con bordes bien definidos y de tamaño esperado. Aun así, se evidenció que no todos los pinholes se revelan al mismo tiempo, ocasionando que una minoría permanezca sin destapar o destapados a medias. Además de esto, se observó un afectación de los recubrimientos en el borde del disco. Todo esto puede ser causa de la agresividad de la solución o de problemas con el recubrimiento de plata. Por esta razón se planea continuar realizando pruebas para caracterizar el proceso y así encontrar los mejores parámetros y la mejor concentración de la solución para obtener un mejor resultado.

a)

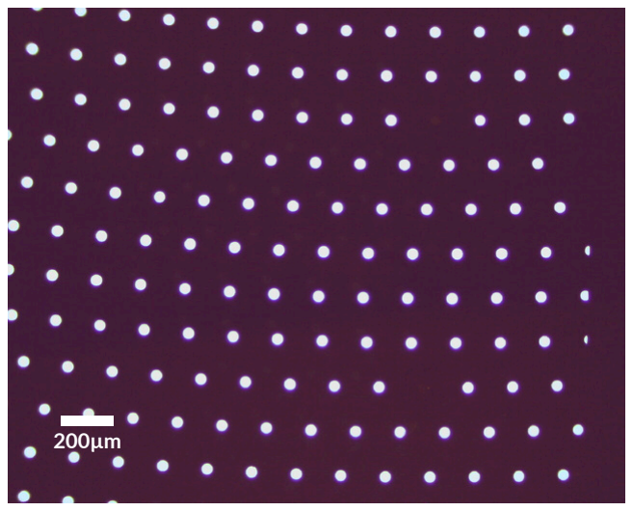
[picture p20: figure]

b)

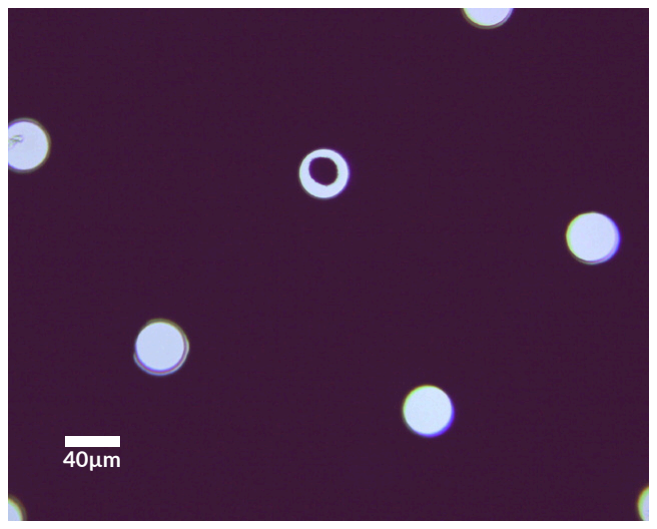
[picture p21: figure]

Figura 5: Fotografías de los pinholes fabricados. Se observan en a) un par de pinholes sin revelar y en b) uno que no se reveló por completo.

V. AGRADECIMIENTOS

Agradecemos a la Universidad Nacional y, en especial, al profesor Ricardo Amézquita, así como a su equipo de investigación de la empresa Combustión Ingenieros, Jefferson, Jorge, Oscar y Andrés, por el apoyo brindado y ´ por facilitar los equipos necesarios para la fabricación del disco.

REFERENCIAS

[1] D. K. Toomre, M. F. Langhorst, and M. W. Davidson, “Introduction to spinning disk confocal microscopy.” https://zeiss-campus.magnet.fsu.edu/articles/spinningdisk/introduction.html, (https://zeiss-campus.magnet.fsu.edu/articles/spinningdisk/introduction.html) 2009. Accedido: Dic-2025.
[2] M. Petráň and M. Hadravsky, “Tandem-Scanning Reflected-Light Microscope,” Journal of The Optical Society of America, vol. 58, May 1968.
[3] A. R. Halpern, M. Y. Lee, M. D. Howard, M. A. Woodworth, P. R. Nicovich, and J. C. Vaughan, “Versatile. doit-yourself, low-cost spinning disk confocal microscope,” Biomedical Optics Express, vol. 13, Feb. 2022.
[4] D. Fewer, S. Hewlett, and E. M. McCabe, “Laser sources in direct-view-scanning, tandem-scanning, or Nipkow-diskscanning confocal microscopy,” Applied Optics, vol. 37, Jan. 1998.
[5] Room and H. E. Materials, “Microposit™ s1818™ positive
photoresist | datasheet.” | https://www.nano.pitt.edu/
sites/default/files/S1818_photoresist.pdf, (https://www.nano.pitt.edu/sites/default/files/S1818_photoresist.pdf) | 2004.
Accedido: Dic-2025.
[6] F. Okamoto, “Etching solution for silver,” 1975.

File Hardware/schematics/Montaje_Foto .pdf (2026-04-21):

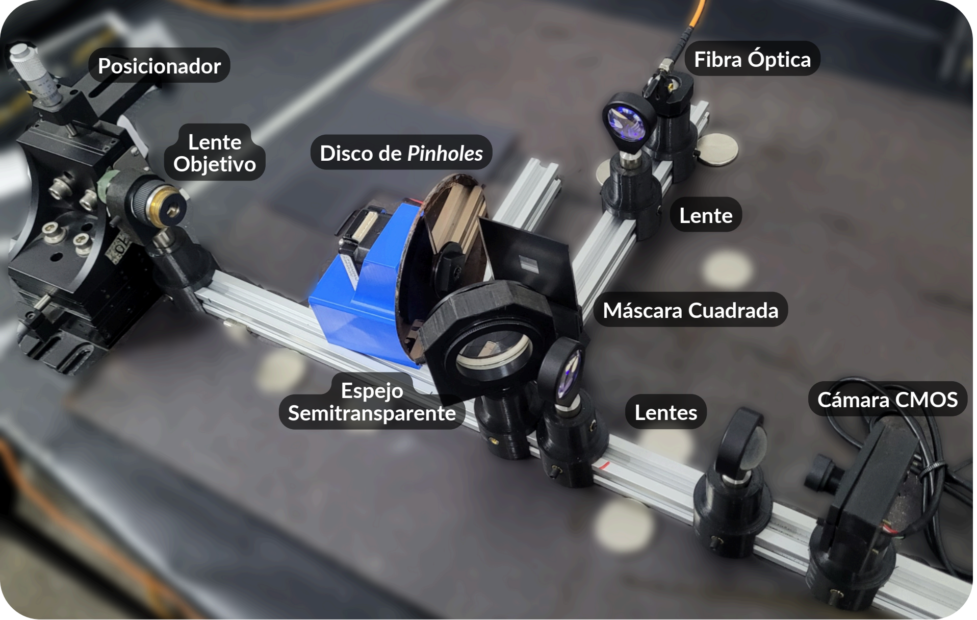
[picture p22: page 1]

Fibra Óptica

Lente

Máscara Cuadrada

Espejo
Semitransparente

Cámara CMOS

Disco de Pinholes

Lente
Objetivo

Posicionador

Lentes

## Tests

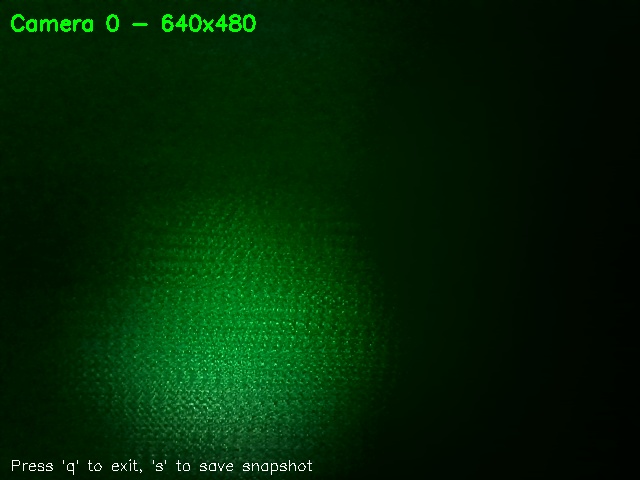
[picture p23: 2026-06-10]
Software/nipkowArduino/test/export/snapshot_20251127_165409_9.jpg

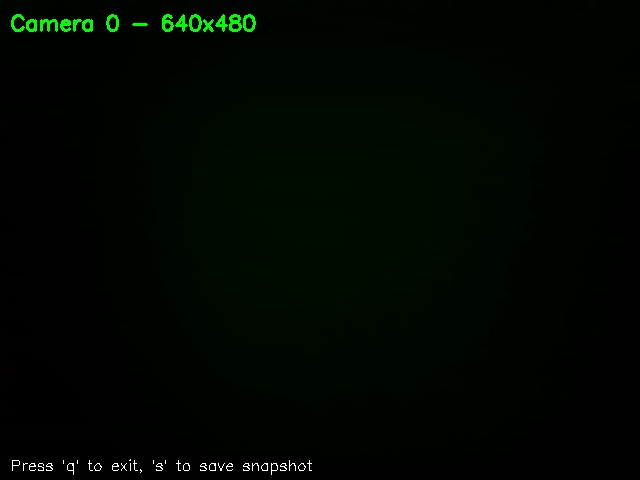
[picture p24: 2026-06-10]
Software/nipkowArduino/test/export/snapshot_20251127_160423_3.jpg

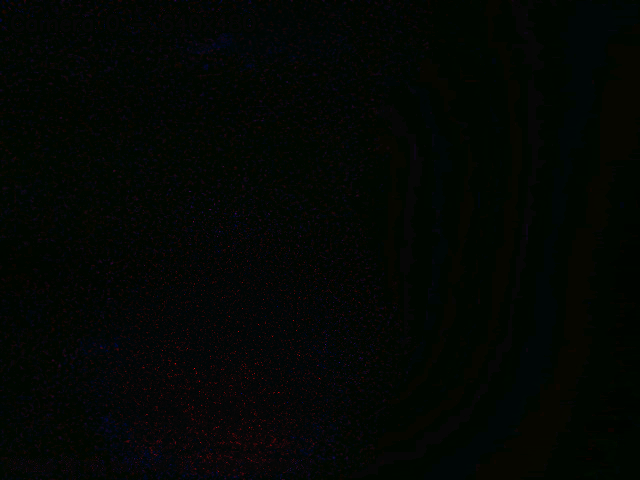
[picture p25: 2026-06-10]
Software/nipkowArduino/test/export/cociente.png

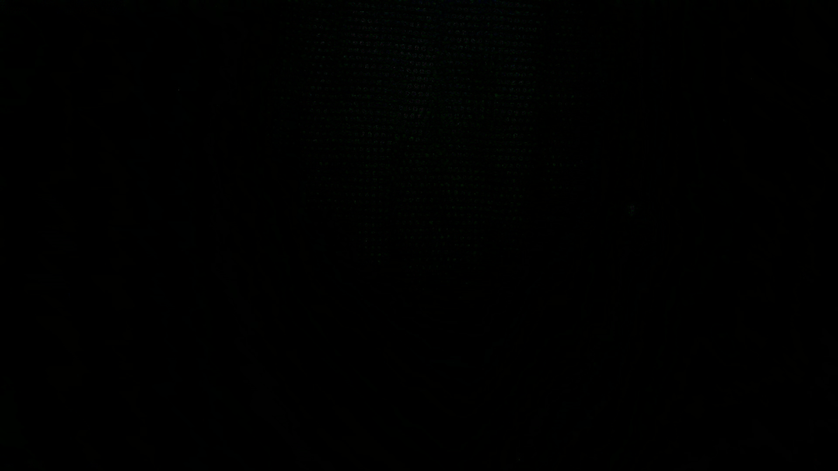
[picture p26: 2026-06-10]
Software/nipkowArduino/test/export/resta_absoluta.png

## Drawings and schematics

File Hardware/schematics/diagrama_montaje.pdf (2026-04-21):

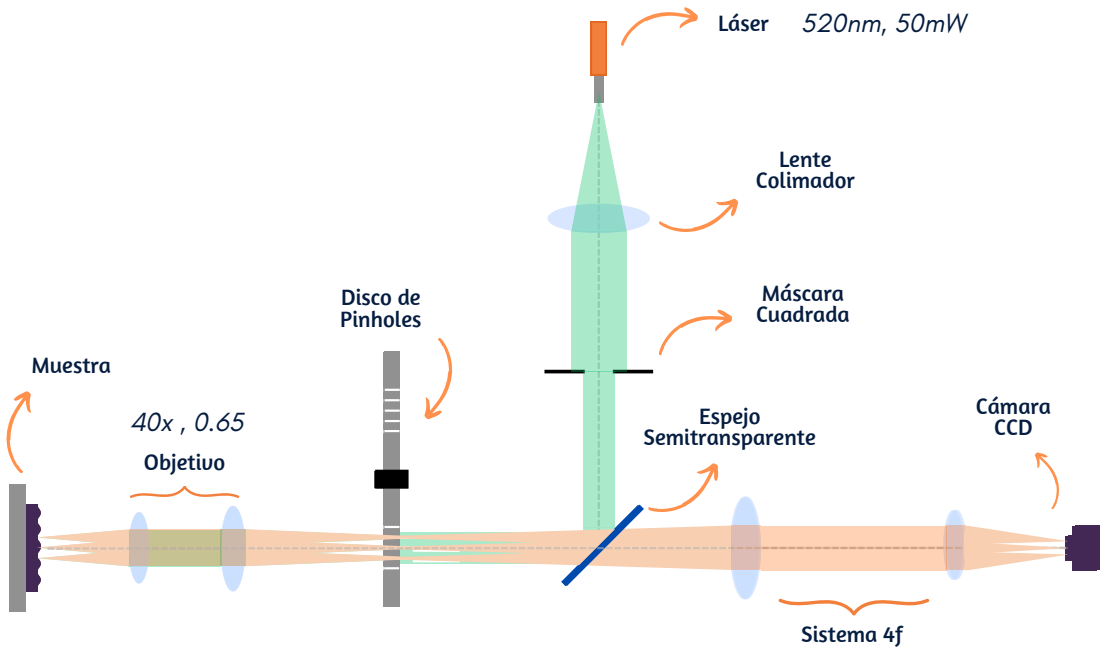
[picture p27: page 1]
Láser; Lente Colimador; Cámara CCD; Espejo Semitransparente; Disco de Pinholes; Objetivo; Muestra; Máscara Cuadrada; Sistema 4f

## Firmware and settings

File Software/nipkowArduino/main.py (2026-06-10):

"""
Main Application - Stepper Motor and Camera Control System
Unified interface for controlling stepper motor and USB camera.
Command-line interface with short descriptive commands.
"""

import sys
import os
from datetime import datetime
import serial
import platform
from stepper_control import StepperController
from camera_controller import CameraController

# For listing available ports
try:
    import serial.tools.list_ports
except ImportError:
    serial = None

class MainController:
    def __init__(self):
        """Initialize main controller."""
        self.stepper = None
        self.camera = None
        self.running = True
        
    def setup_stepper(self, port='COM3', baudrate=9600):
        """Initialize stepper motor controller."""
        try:
            self.stepper = StepperController(port=port, baudrate=baudrate)
            return True
        except Exception as e:
            print(f"[ERROR] Error initializing stepper: {e}")
            return False
    
    def setup_camera(self, camera_index=None):
        """Initialize camera controller."""
        self.camera = CameraController()
        return self.camera.connect_camera(camera_index)
    
    def parse_command(self, cmd_line):
        """Parse command line into command and arguments."""
        parts = cmd_line.strip().split()
        if not parts:
            return None, []
        return parts[0].lower(), parts[1:]
    
    def show_help(self):
        """Display help information."""
        print("\n" + "="*60)
        print("  AVAILABLE COMMANDS")
        print("="*60)
        print("\nCONNECTION:")
        print("  connect <PORT>              - Connect to Arduino (e.g., connect COM3)")
        print("  list-ports                  - List active serial ports (COM/ttyUSB)")
        print("  cam                         - Connect to camera (auto-detect)")
        print("  cam <INDEX>                 - Connect to specific camera")
        print("  disconnect                  - Disconnect all devices")
        
        print("\nSTEPPER MOTOR:")
        print("  speed <RPM>                 - Set motor speed (e.g., speed 100)")
        print("  stop                        - Stop motor immediately")
        print("  status                      - Show motor status")
        
        print("\nCAMERA:")
        print("  capture <N> <EXP> avg       - Capture N images, exposure EXP ms, average")
        print("  capture <N> <EXP> sum       - Capture N images, exposure EXP ms, sum")
        print("  live                        - Show live video feed")
        print("  list-cam                    - List available cameras")
        
        print("\nSYSTEM:")
        print("  info                        - Show system status")
        print("  help                        - Show this help")
        print("  exit                        - Exit program")
        print("="*60)
        
        print("\nEXAMPLES:")
        print("  connect COM3                - Connect to Arduino on COM3")
        print("  list-ports                  - Show all available COM ports")
        print("  speed 150                   - Set motor to 150 RPM")
        print("  live                        - Show live camera feed")
        print("  capture 10 100 avg          - Capture 10 images, 100ms exposure, average them")
        print("  capture 20 50 sum           - Capture 20 images, 50ms exposure, sum them")
        print("="*60 + "\n")
    
    def cmd_list_ports(self, args):
        """Handle list-ports command - list available serial ports."""
        print("\nScanning for active serial ports...\n")
        
        try:
            from serial.tools.list_ports import comports
            
            ports = comports()
            
            if not ports:
                print("No serial ports detected.")
                print("\nOn Linux, look for:")
                print("  - /dev/ttyUSB0, /dev/ttyUSB1, etc. (USB devices)")
                print("  - /dev/ttyACM0, /dev/ttyACM1, etc. (Arduino)")
                print("\nOn Windows, look for COM3, COM4, etc.")
                return
            
            print(f"Found {len(ports)} serial port(s):\n")
            
            for i, port in enumerate(ports, 1):
                print(f"  [{i}] {port.device}")
                if port.description:
                    print(f"      Description: {port.description}")
                if port.manufacturer:
                    print(f"      Manufacturer: {port.manufacturer}")
                if port.product:
                    print(f"      Product: {port.product}")
                print()
            
            print("Usage: connect <PORT>")
            print("  Example: connect /dev/ttyACM0")
            print("  Example: connect COM3")
            print()
            
        except Exception as e:
            print(f"[ERROR] Failed to list ports: {e}")
            print("\nTrying fallback method...")
            self._list_ports_fallback()
    
    def _list_ports_fallback(self):
        """Fallback method to list ports."""
        import os
        import glob
        
        os_name = platform.system()
        
        if os_name == "Linux":
            print("\nLinux ports detected:")
            usb_ports = glob.glob('/dev/ttyUSB*')
            acm_ports = glob.glob('/dev/ttyACM*')
            
            all_ports = sorted(usb_ports + acm_ports)
            
            if all_ports:
                for port in all_ports:
                    print(f"  - {port}")
            else:
                print("  No USB or ACM ports found")
                
        elif os_name == "Windows":
            print("\nWindows COM ports detected:")
            for i in range(256):
                port = f"COM{i}"
                try:
                    s = serial.Serial(port)
                    print(f"  - {port}")
                    s.close()
                except:
                    pass
        
        elif os_name == "Darwin":  # macOS
            print("\nmacOS ports detected:")
            usb_ports = glob.glob('/dev/tty.usbserial*')
            usbmodem_ports = glob.glob('/dev/tty.usbmodem*')
            
            all_ports = sorted(usb_ports + usbmodem_ports)
            
            if all_ports:
                for port in all_ports:
                    print(f"  - {port}")
            else:
                print("  No USB ports found")
        
        print()
    
    def cmd_connect(self, args):
        """Handle connect command."""
        if not args:
            print("[ERROR] Usage: connect <PORT>")
            print("   Example: connect COM3")
            return
        
        port = args[0]
        print(f"Connecting to {port}...")
        if self.setup_stepper(port=port):
            print(f"Connected to stepper on {port}")
    
    def cmd_cam(self, args):
        """Handle cam command."""
        camera_index = None
        if args:
            try:
                camera_index = int(args[0])
            except ValueError:
                print("[ERROR] Invalid camera index")
                return
        
        print("Connecting to camera...")
        if self.setup_camera(camera_index):
            info = self.camera.get_camera_info()
            print(f"Camera connected: Index {info.get('index')}, {info.get('width')}x{info.get('height')}")
    
    def cmd_disconnect(self, args):
        """Handle disconnect command."""
        print("Disconnecting devices...")
        if self.stepper:
            self.stepper.close()
            self.stepper = None
        if self.camera:
            self.camera.close()
            self.camera = None
        print("Disconnected")
    
    def cmd_speed(self, args):
        """Handle speed command."""
        if not self.stepper:
            print("[ERROR] Stepper not connected. Use: connect <PORT>")
            return
        
        if not args:
            print("[ERROR] Usage: speed <RPM>")
            print("   Example: speed 100")
            return
        
        try:
            rpm = int(args[0])
            self.stepper.set_speed(rpm)
        except ValueError:
            print("[ERROR] Invalid RPM value")
    
    def cmd_stop(self, args):
        """Handle stop command."""
        if not self.stepper:
            print("[ERROR] Stepper not connected")
            return
        
        print("Stopping motor...")
        self.stepper.stop()
    
    def cmd_status(self, args):
        """Handle status command."""
        if not self.stepper:
            print("[ERROR] Stepper not connected")
            return
        
        status = self.stepper.get_status()
        print("\nMotor Status:")
        print(f"   Speed: {status['speed']} RPM")
        print(f"   State: {status['direction']}")
        print(f"   Running: {'Yes' if status['running'] else 'No'}\n")
    
    def cmd_capture(self, args):
        """Handle capture command."""
        if not self.camera:
            print("[ERROR] Camera not connected. Use: cam")
            return
        
        if len(args) < 3:
            print("[ERROR] Usage: capture <N> <EXPOSURE_MS> <avg|sum>")
            print("   Example: capture 10 100 avg")
            return
        
        try:
            num_images = int(args[0])
            exposure_time = float(args[1])
            mode = args[2].lower()
            
            if mode not in ['avg', 'average', 'sum']:
                print("[ERROR] Mode must be 'avg' or 'sum'")
                return
            
            print(f"Starting capture: {num_images} images @ {exposure_time}ms...")
            images, stats = self.camera.capture_multiple(num_images, exposure_time)
            
            if not images:
                print("[ERROR] No images captured")
                return
            
            # Process images
            if mode in ['avg', 'average']:
                result = self.camera.average_images(images)
                operation = "averaged"
            else:
                result = self.camera.sum_images(images, normalize=True)
                operation = "summed"
            
            if result is not None:
                timestamp = datetime.now().strftime("%Y%m%d_%H%M%S")
                filename = f"output_{operation}_{timestamp}.jpg"
                self.camera.save_image(result, filename)
                print(f"Successfully {operation} {num_images} images -> {filename}")
                
                # Ask if user wants to save stats
                save_stats = input("\nSave timing statistics to file? (y/n): ").strip().lower()
                if save_stats == 'y':
                    self.camera.save_capture_stats()
                print()
                
        except ValueError:
            print("[ERROR] Invalid parameters")
    
    def cmd_live(self, args):
        """Handle live video command."""
        if not self.camera:
            print("[ERROR] Camera not connected. Use: cam")
            return
        
        self.camera.show_live_video()
    
    def cmd_list_cam(self, args):
        """Handle list-cam command."""
        print("\nDetecting cameras...")
        temp_cam = CameraController()
        cameras = temp_cam.detect_cameras()
        
        if cameras:
            print(f"Found {len(cameras)} camera(s):")
            for idx in cameras:
                print(f"  - Camera index: {idx}")
        else:
            print("No cameras detected")
        print()
    
    def cmd_info(self, args):
        """Handle info command."""
        print("\n" + "="*50)
        print("SYSTEM STATUS")
        print("="*50)
        
        # Stepper status
        if self.stepper is not None:
            status = self.stepper.get_status()
            print(f"[OK] Stepper: Connected")
            print(f"  Speed: {status['speed']} RPM")
            print(f"  State: {status['direction']}")
        else:
            print("[--] Stepper: Not connected")
        
        # Camera status
        if self.camera is not None and self.camera.camera is not None:
            info = self.camera.get_camera_info()
            print(f"[OK] Camera: Connected (Index {info.get('index', 'N/A')})")
            print(f"  Resolution: {info.get('width', 0)}x{info.get('height', 0)}")
        else:
            print("[--] Camera: Not connected")
        print("="*50 + "\n")
    
    def cmd_exit(self, args):
        """Handle exit command."""
        print("\nShutting down...")
        self.running = False
    
    def process_command(self, cmd_line):
        """Process a command line."""
        cmd, args = self.parse_command(cmd_line)
        
        if cmd is None:
            return
        
        # Command dispatch
        commands = {
            'connect': self.cmd_connect,
            'list-ports': self.cmd_list_ports,
            'cam': self.cmd_cam,
            'disconnect': self.cmd_disconnect,
            'speed': self.cmd_speed,
            'stop': self.cmd_stop,
            'status': self.cmd_status,
            'capture': self.cmd_capture,
            'live': self.cmd_live,
            'list-cam': self.cmd_list_cam,
            'info': self.cmd_info,
            'help': lambda args: self.show_help(),
            'exit': self.cmd_exit,
            'quit': self.cmd_exit,
            '?': lambda args: self.show_help(),
        }
        
        if cmd in commands:
            commands[cmd](args)
        else:
            print(f"[ERROR] Unknown command: {cmd}")
            print("Type 'help' for available commands")
    
    def run(self):
        """Run main application loop."""
        print("\n" + "="*60)
        print("  ARDUINO STEPPER & CAMERA CONTROL SYSTEM")
        print("="*60)
        print("  Type 'help' for available commands")
        print("="*60 + "\n")
        
        try:
            while self.running:
                try:
                    cmd_line = input(">>> ").strip()
                    if cmd_line:
                        self.process_command(cmd_line)
                except EOFError:
                    break
        
        except KeyboardInterrupt:
            print("\n\n[INTERRUPT] Interrupted by user")
        
        finally:
            self.cleanup()
    
    def cleanup(self):
        """Clean up resources."""
        print("\nCleaning up...")
        
        if self.stepper is not None:
            self.stepper.close()
        
        if self.camera is not None:
            self.camera.close()
        
        print("Goodbye!\n")

def main():
    """Entry point."""
    controller = MainController()
    controller.run()

if __name__ == "__main__":
    main()

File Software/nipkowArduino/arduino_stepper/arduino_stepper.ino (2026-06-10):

/*
 * Stepper Motor Control with TB6560 Driver
 * 
 * Receives speed commands via serial and controls a stepper motor.
 * 
 * Connections:
 * - TB6560 PUL+ (or CLK+) -> Arduino Pin 3
 * - TB6560 DIR+ (or CW+)  -> Arduino Pin 4
 * - TB6560 ENA+ (optional) -> Arduino Pin 5
 * - TB6560 PUL-, DIR-, ENA- -> Arduino GND
 * - TB6560 VCC -> Power supply (12-36V DC)
 * - TB6560 GND -> Power supply GND
 * - TB6560 A+, A-, B+, B- -> Stepper motor coils
 * 
 * Note: TB6560 uses common anode (+) logic
 */

// Pin definitions
const int STEP_PIN = 3;   // PUL+ or CLK+ on TB6560
const int DIR_PIN = 4;    // DIR+ or CW+ on TB6560
const int ENABLE_PIN = 5; // ENA+ on TB6560 (optional)

// Motor parameters
const int STEPS_PER_REVOLUTION = 200;  // Change if your motor has different steps
int currentSpeed = 0;  // Current RPM
unsigned long stepDelay = 0;  // Microseconds between steps

void setup() {
  // Initialize pins
  pinMode(STEP_PIN, OUTPUT);
  pinMode(DIR_PIN, OUTPUT);
  pinMode(ENABLE_PIN, OUTPUT);
  
  // Set direction (HIGH = clockwise, LOW = counterclockwise)
  digitalWrite(DIR_PIN, HIGH);
  
  // Enable the motor (LOW = enabled, HIGH = disabled for TB6560)
  digitalWrite(ENABLE_PIN, LOW);
  
  // Initialize serial communication
  Serial.begin(9600);
  Serial.println("Arduino Stepper Controller Ready (TB6560)");
  Serial.println("Send command: SPEED:xxx (RPM)");
}

void loop() {
  // Check for serial commands
  if (Serial.available() > 0) {
    String command = Serial.readStringUntil('\n');
    command.trim();
    
    if (command.startsWith("SPEED:")) {
      int rpm = command.substring(6).toInt();
      setSpeed(rpm);
      Serial.print("Speed set to ");
      Serial.print(rpm);
      Serial.println(" RPM");
    }
  }
  
  // Step the motor if speed > 0
  if (currentSpeed > 0 && stepDelay > 0) {
    digitalWrite(STEP_PIN, HIGH);
    delayMicroseconds(stepDelay / 2);
    digitalWrite(STEP_PIN, LOW);
    delayMicroseconds(stepDelay / 2);
  }
}

void setSpeed(int rpm) {
  currentSpeed = rpm;
  
  if (rpm == 0) {
    stepDelay = 0;
    // Optionally disable motor
    // digitalWrite(ENABLE_PIN, HIGH);
  } else {
    // Calculate delay between steps
    // delay (microseconds) = 60,000,000 / (RPM * STEPS_PER_REVOLUTION)
    stepDelay = 60000000L / (rpm * STEPS_PER_REVOLUTION);
    
    // Enable motor if it was disabled
    digitalWrite(ENABLE_PIN, LOW);
  }
}
